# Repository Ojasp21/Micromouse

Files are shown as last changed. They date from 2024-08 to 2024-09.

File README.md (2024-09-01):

# Micromouse
Design a micromouse PCB from scratch and implement maze floodfill algorithms on it!  

## Table of Contents

- [Micromouse](#micromouse)
  - [Table of Contents](#table-of-contents)
  - [About The Project](#about-the-project)
  - [Project Workflow](#project-workflow)
  - [Hardware Used](#hardware-used)
  - [Perfboard Testing](#perfboard-testing)
  - [PCB Model](#pcb-model)
  - [CAD Models](#cad-models)
    - [Features](#features)
  - [Floodfill Algorithm Simulation](#floodfill-algorithm-simulation)
  - [Software Used](#software-used)
  - [Future Work](#future-work)
  - [Contributors](#contributors)
  - [Resources](#resources)
  - [Acknowledgements](#acknowledgements)
  - [License](#license)

## About The Project
The aim of this project is to design and assemble a full size micromouse which will use floodfill and other path finding algorithms to solve a maze.    

The dimensions of our full-size micromouse is 11.5 x 10 cm

## Project Workflow  
#### Research
- Learning and understanding Embedded C by referring to the firmware used in [SRA WallE](https://github.com/SRA-VJTI/Wall-E) and [MazeBlaze](https://github.com/SurajSonawane2415/MazeBlaze)
- Understanding what Micromouse is and how maze solving algorithms like floodfill actually work
- Deciding the constraints for our micrmouse and selecting hardware and electronic componenets accordingly. We did a detailed review of existing micromouse designs and features and arrived at our present design.
#### CAD and PCB Design
- Designing a CAD Model on [Onshape.com](https://www.onshape.com/en/). We went through various iterations and design options. After weighing the pro's and cons of a 4 motor design, we settled for a 2 motor design with a suction fan in the centre.
- PCB Design keeping mechanical design in mind during routing. Once the pcb design and routing is finalised, the order for the PCB is placed.
#### Perfboard Testing and PID
- Testing our pcb schematic on a perfboard and recreating the final micromouse design on a perfboard.
- Implementing PID on the perfboard Micromouse to refine the code and understand the implementation of control systems.
#### PCB Soldering and Assembly
- Once the PCB is delivered, we will solder the components onto the PCB and assemble the bot with the 3D-printed mounts
- After this, the testing of the final Micromouse in a 6ft x 6ft maze will begin.

## Hardware Used

| Components | Description |
| --- | --- |
| [ESP32 WROOM-E](https://robu.in/product/espressif-esp32-wroom-32e-16m-128mbit-flash-wifi-bluetooth-module/) | Microcontroller |
| [VL 5310X](https://robu.in/product/gy-53-vl53l0x-laser-tof-flight-time-ranging-sensor-module-serial-port-pwm-output/)  | ToF sensor4 |
| [DRV8833](https://robu.in/product/drv8833-2-channel-dc-motor-driver-module/) | Motor Driver |
| [N12 600 RPM With Encoders](https://robu.in/product/n12-2-4v-1200rpm-metal-gear-motor-with-encoder/) | Motors |
| [IR Sensors](https://robocraze.com/products/5mm-ir-transmitter-receiver-pair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) | Infrared Emitter-Receiver Pair |

## Perfboard Testing
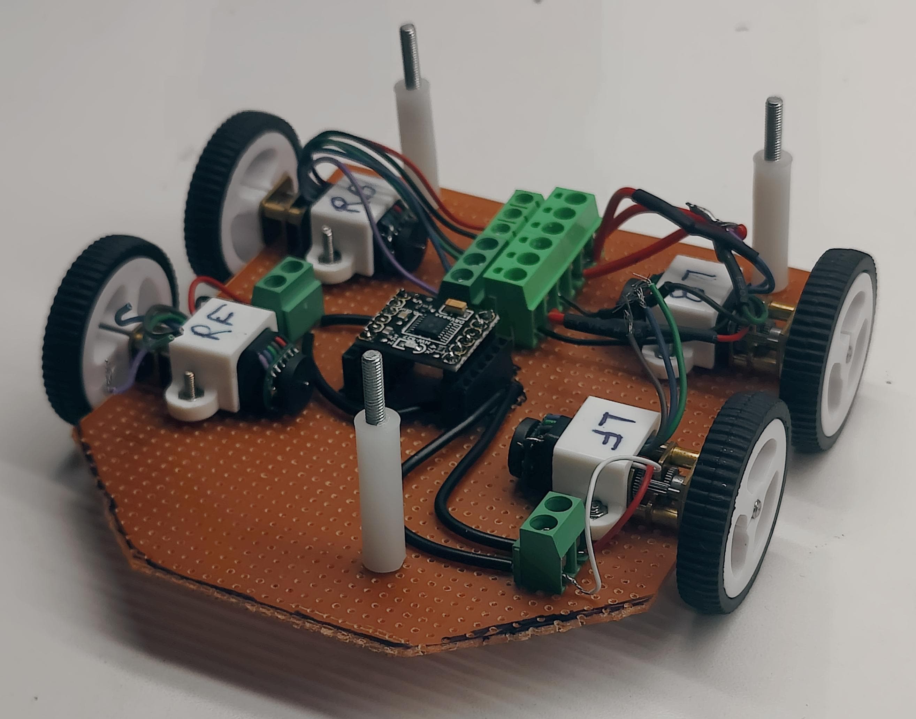
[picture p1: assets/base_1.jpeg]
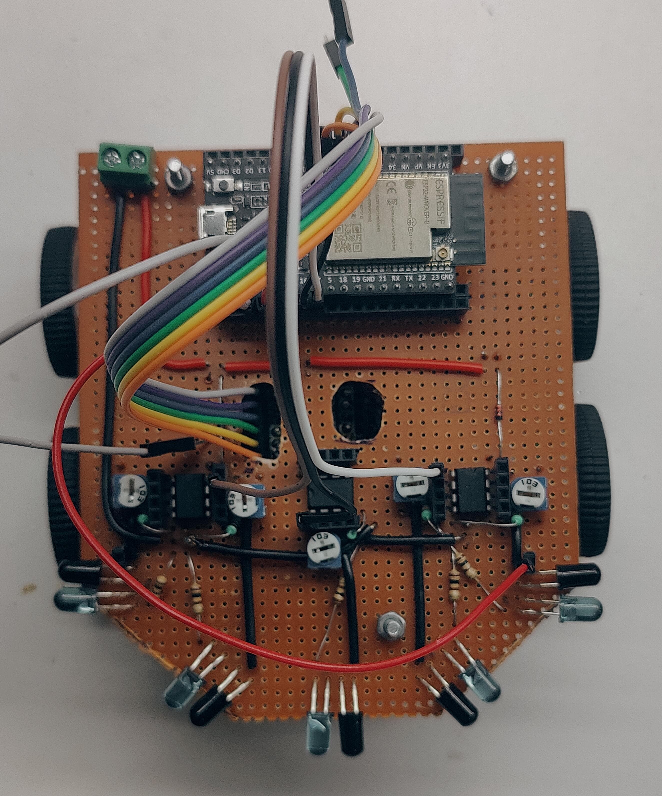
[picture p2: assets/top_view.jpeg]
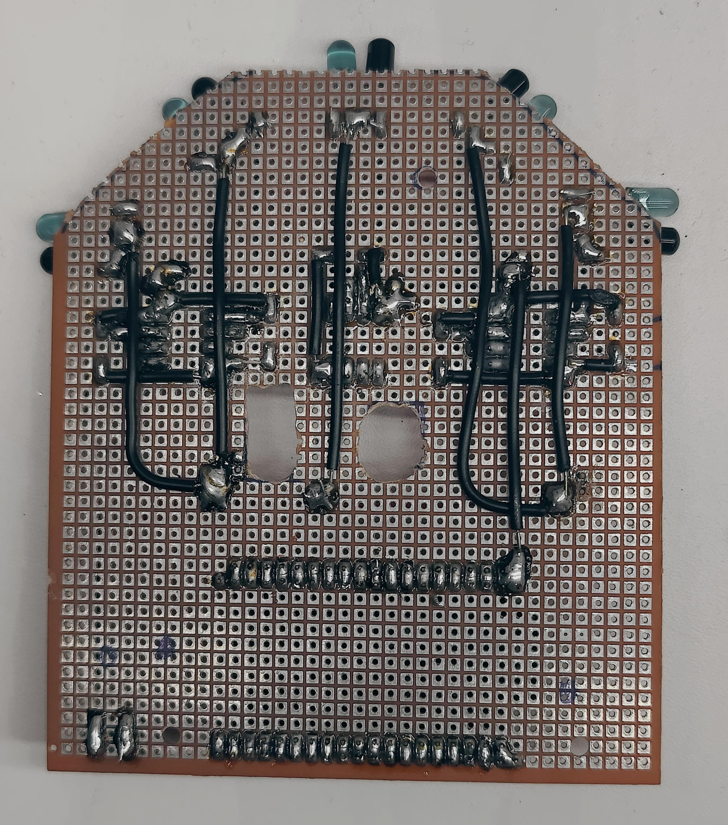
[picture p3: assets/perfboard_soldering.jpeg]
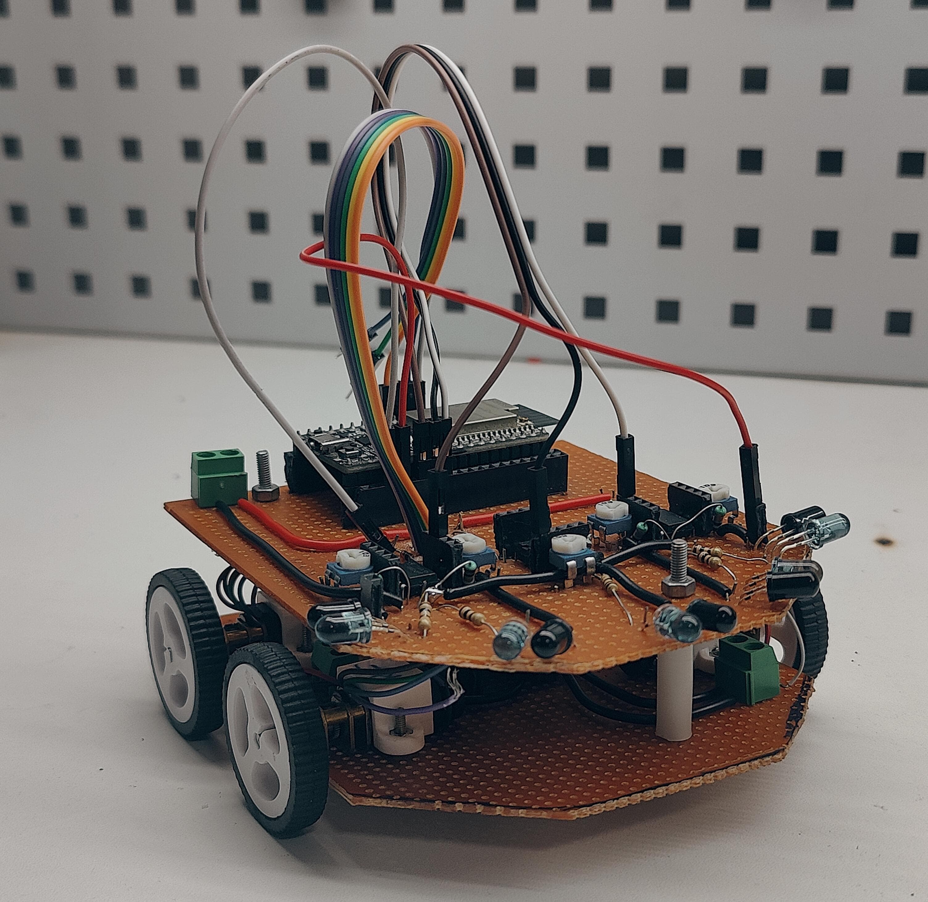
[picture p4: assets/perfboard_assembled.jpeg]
|             |  |  |  |
:-------------------------:|:-------------------------:|:-------------------------:|:-------------------------:

## PCB Model
- View of the PCB Model front and back:       
  
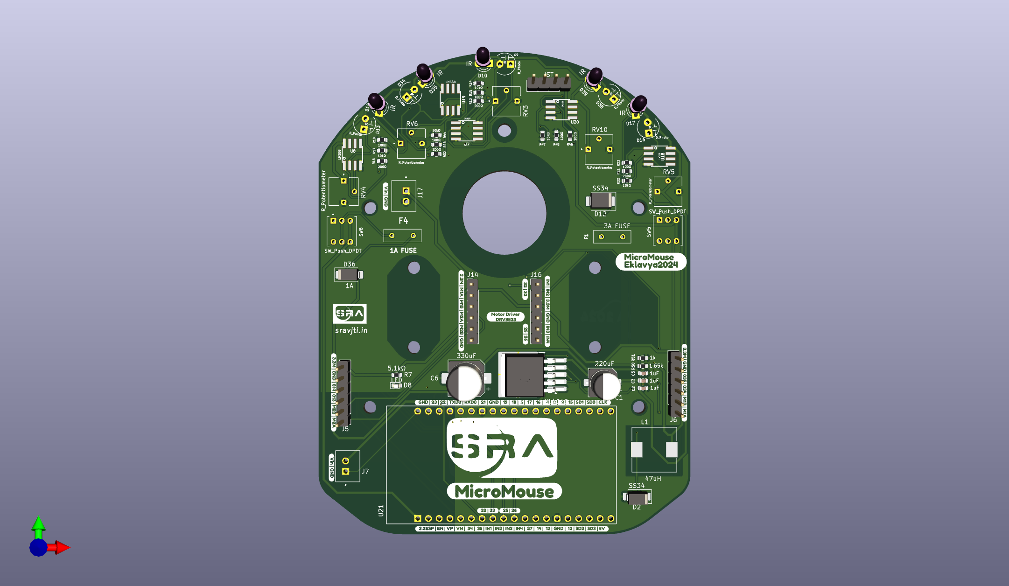
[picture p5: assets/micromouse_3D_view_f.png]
pcb_model_front
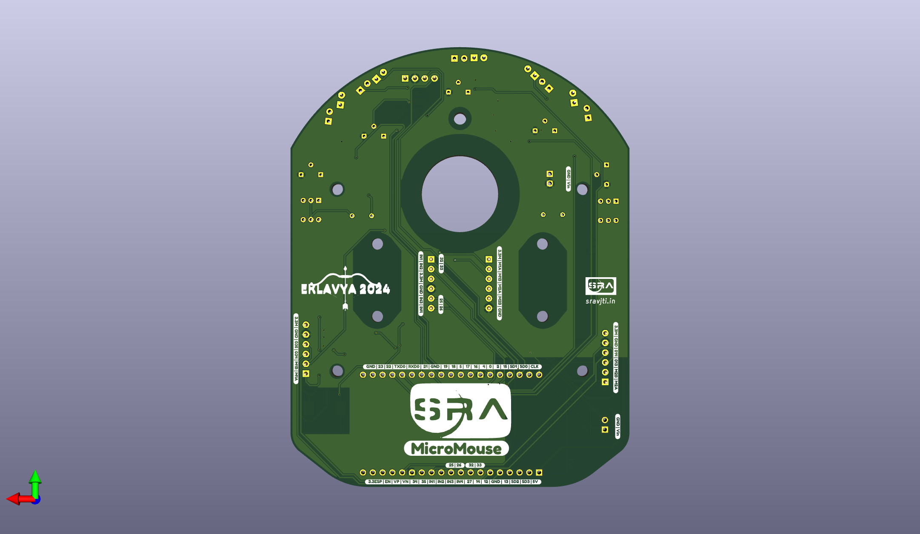
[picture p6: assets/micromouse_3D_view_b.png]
pcb_model_back
|             |  |    
:-------------------------:|:-------------------------:|

- View of the PCB Routing - front and back:      
  
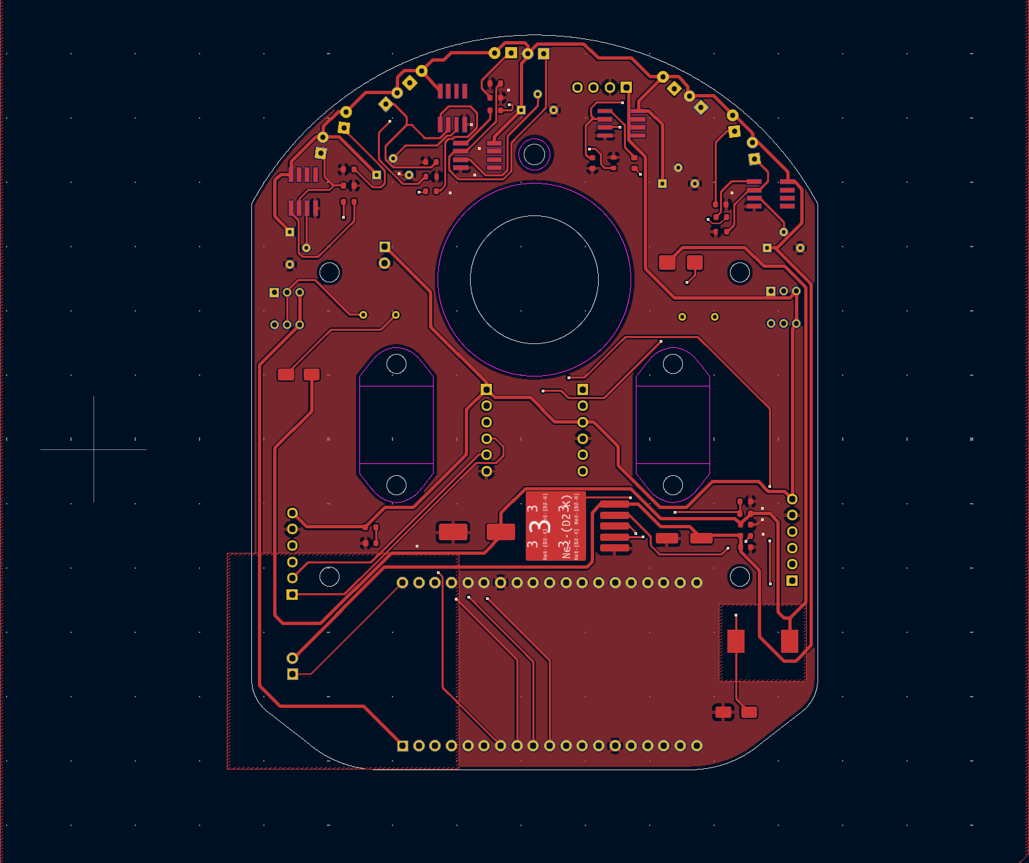
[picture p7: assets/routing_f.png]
pcb_routing_front
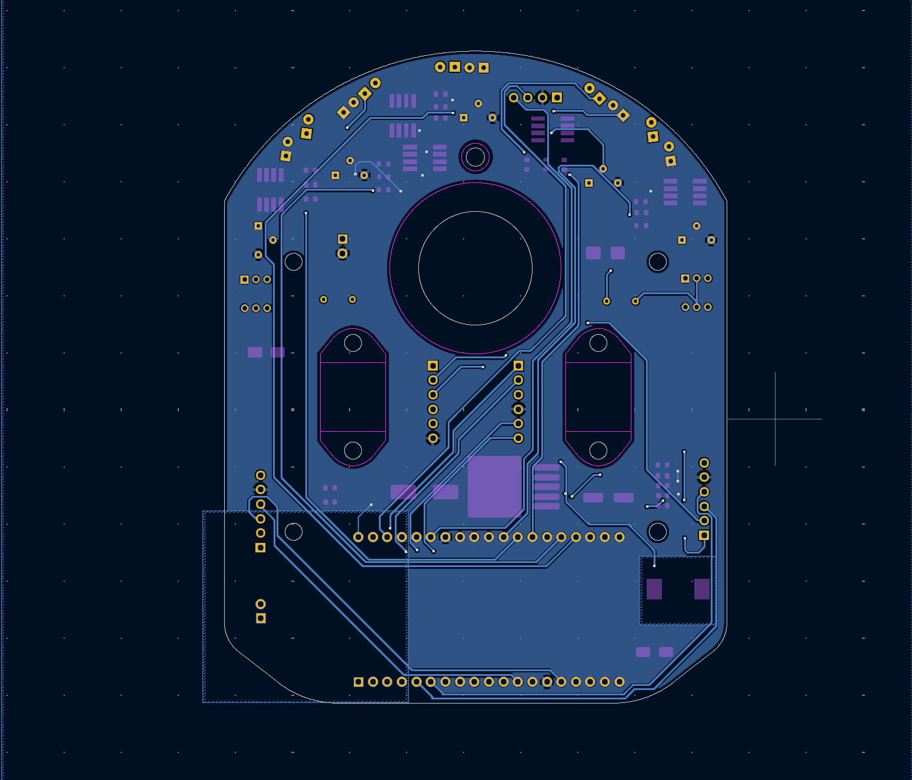
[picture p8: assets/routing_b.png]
pcb_routing_back
|             |  |  
:-------------------------:|:-------------------------:|

## CAD Models 
- First design iteration was a four motor design with a suction fan. However this design was not suitable for fitting an enitre Esp-Devkit. 

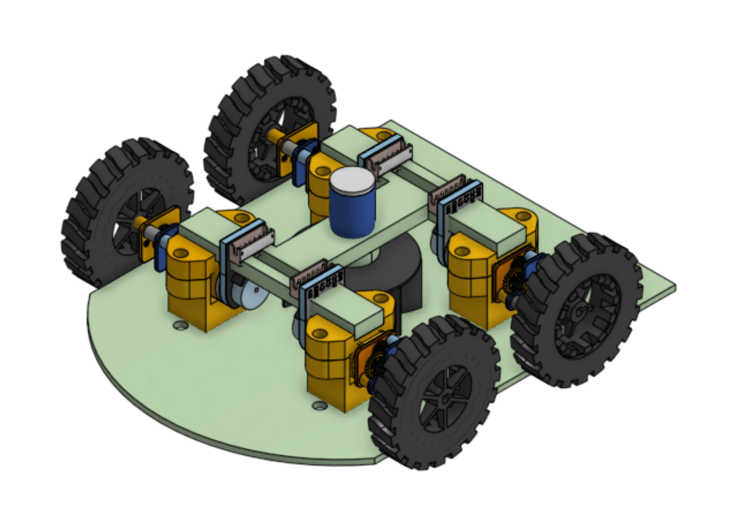
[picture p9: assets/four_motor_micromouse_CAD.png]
four_motor_design
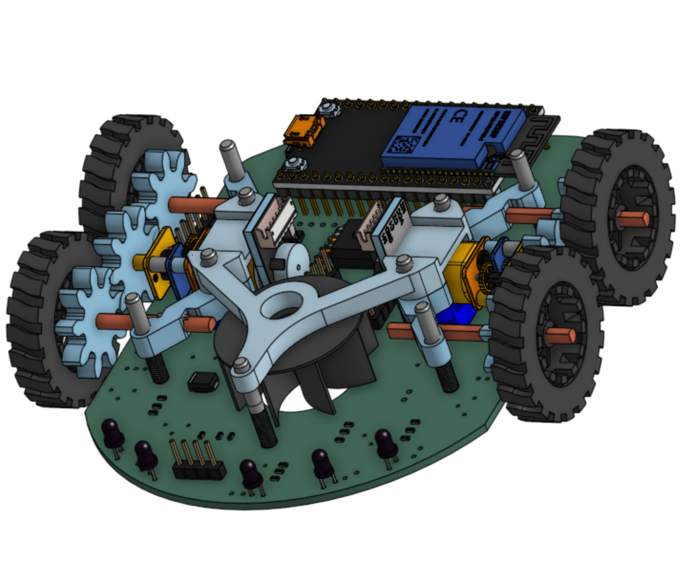
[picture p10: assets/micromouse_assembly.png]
two_motor_design
|             |  |  
:-------------------------:|:-------------------------:|

- Second and final design is a two-motor design with a suction fan. Certain drawbacks of the four-motor design was addressed in this design.  
<p align="center">
  
</p>

### Features 
- Suction Fan to improve traction and potentially turn at faster speeds without flipping over.  
- Custom mount to hold the motors, shaft and suction fan in place and reduce the distance between the plate and the ground.
-  Gears to run 4 wheels on two motors  
  
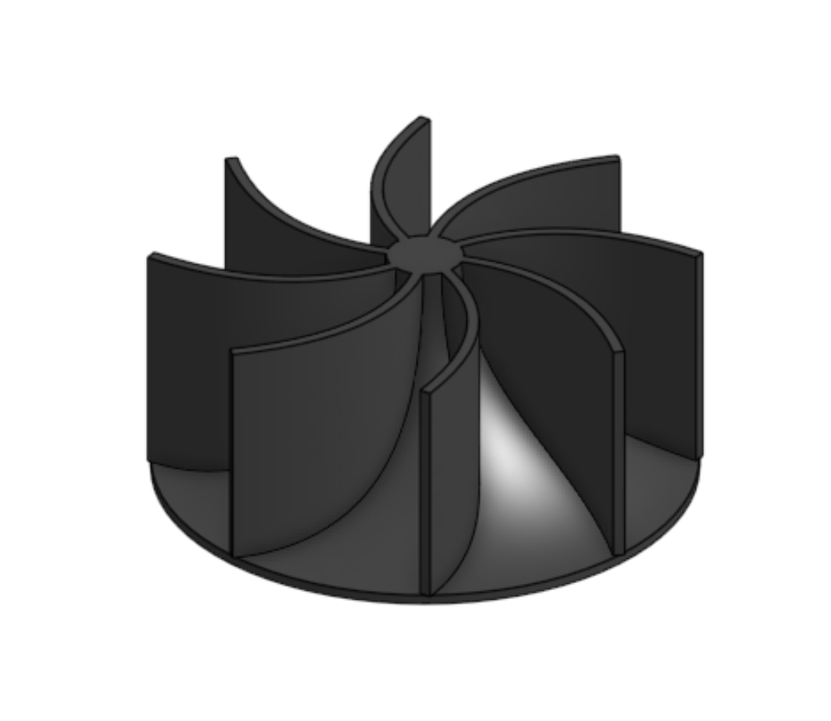
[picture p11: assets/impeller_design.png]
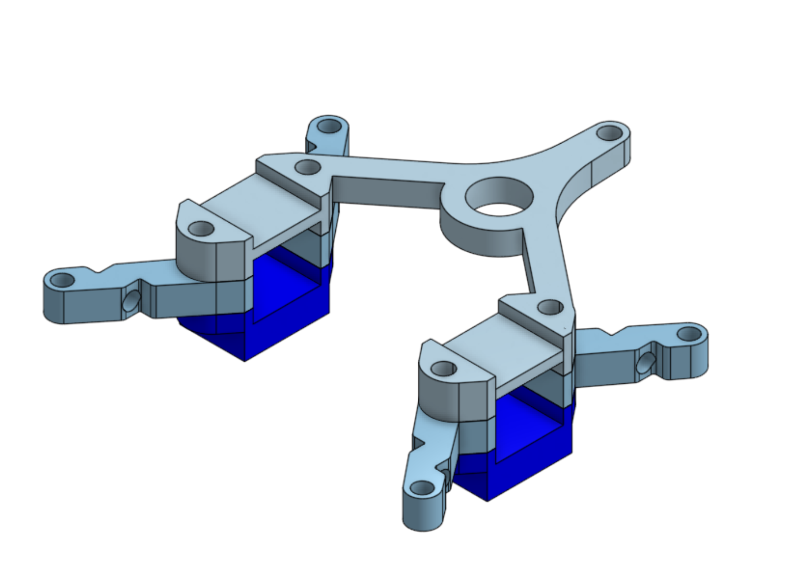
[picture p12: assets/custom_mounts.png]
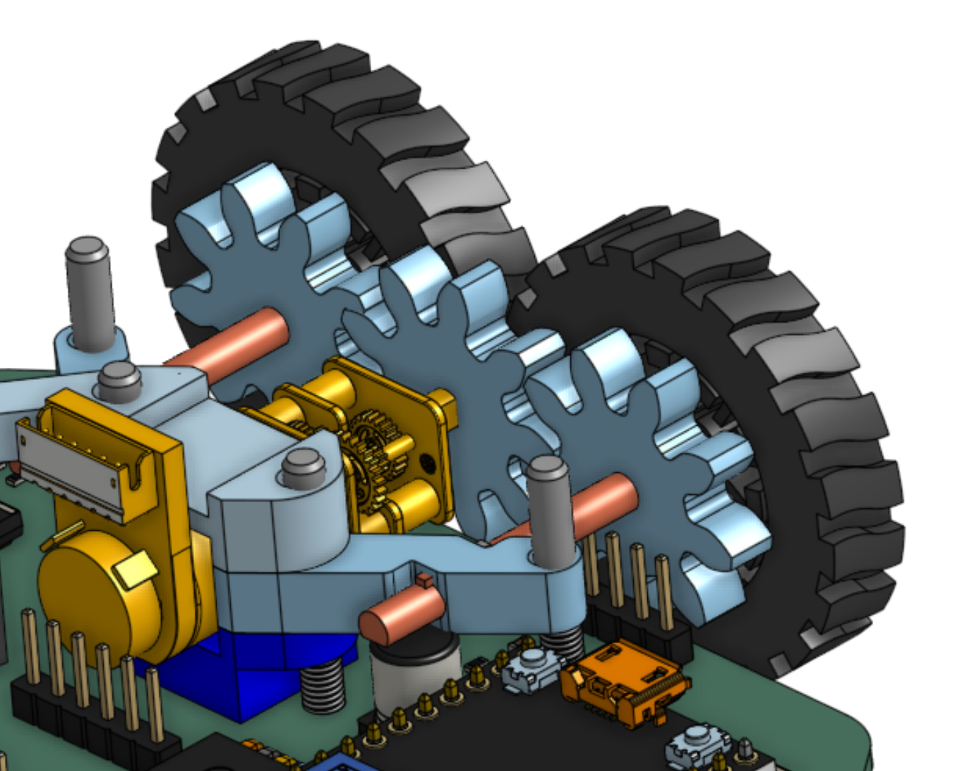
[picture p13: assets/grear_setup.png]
|             |  |  |
:-------------------------:|:-------------------------:|:-------------------------:|
  
## Floodfill Algorithm Simulation
The path solving algorithm floodfill has been successfully implemented in the software simulation.  
[Floodfill simulation](https://github.com/Ojasp21/Micromouse/blob/main/assets/flood%20fill%20simulation.mov)

## Software Used 
- Mechanical Design - [Onshape](https://www.onshape.com/en/)
- PCB Design - [KiCad 8.0.4](https://www.kicad.org/)
- Embedded C and Firmware - [ESP-IDF](https://docs.espressif.com/projects/esp-idf/en/stable/esp32/get-started/index.html)

## Future Work
- [ ] Implementing the flood-fill algorithm on it
- [ ] Optimizing the bot to achieve high speeds and taking turns as diagonals

## Contributors
- [Ojas Patil](https://github.com/Ojasp21)
- [Varun Nigudkar](https://github.com/fluffysunfish)
- [Vishal Mutha ](https://github.com/Vishal-Mutha)

## Resources
- [UCLA Micromouse Playlist](https://www.youtube.com/playlist?list=PLAWsHzw_h0iiPIaGyXAr44G0XfHfyjOe7) 
- [Mushak Github Repository](https://github.com/gautam-dev-maker/mushak/tree/main)
- [Mackorone MMS Github Repository](https://github.com/mackorone/mms) to run and test the floodfill simulation.

## Acknowledgements 
- [SRA VJTI](https://sravjti.in/) Eklavya 2024
- Special thanks to our mentors [Atharva Atre](https://github.com/AtharvaAtre), [Suraj Sonawane](https://github.com/SurajSonawane2415), and all the seniors at SRA, VJTI for their constant support and guidance throughout the project.

## License
[MIT License](https://opensource.org/license/mit/)

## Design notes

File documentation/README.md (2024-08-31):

# *DOCUMENTATION*
Documentation for presentation of [EKLAVYA-SRA](https://eklavya.sravjti.in/projects/) project - [MICROMOUSE](https://eklavya.sravjti.in/projects/Micromouse/) 

## **What is Micromouse?**  
Micromouse is a small, autonomous robot designed to navigate and solve a maze. It is a popular robotics competition where participants build and program a robot (“mouse”) to autonomously find its way from a starting point to the center of a maze in the shortest possible time. The competition combines aspects of ***robotics, algorithm development, and engineering design***, making it a challenging and educational project for students, hobbyists, and professionals alike.  

----

### **Key Objectives of a Micromouse Competition:**  
The primary goal in a Micromouse competition is to design a robot that can:  
- **Autonomously Navigate:** The Micromouse must move through a maze without human intervention. It relies on onboard sensors, microprocessors, and algorithms to make decisions in real-time.  
  
-	**Efficiently Solve the Maze:** The robot must find the shortest or fastest route to the goal, usually the center of the maze, from a starting corner. This involves exploring unknown paths, detecting dead-ends, and backtracking when necessary.  

-	**Optimize Time and Path:** The robot’s success is typically measured by the time it takes to reach the goal and the efficiency of the path taken. Robots are expected to minimize turns, backtracks, and wall collisions to achieve the fastest time.

### **Core Components of a Micromouse:**  
1.	**Microcontroller**: Acts as the “brain” of the robot, processing inputs from sensors and executing maze-solving algorithms. Common microcontrollers used are Arduino, ESP32, or STM32.

2.	**Sensors**: Typically, Infrared (IR) sensors or Time-of-Flight (ToF) sensors are used to detect walls and measure distances, helping the robot navigate through the maze accurately.

3.	**Motors and Motor Drivers**: The Micromouse uses small DC motors or stepper motors for movement, controlled by motor drivers like the DRV8833, which regulate speed and direction.

4.	**Algorithms**: Efficient maze-solving algorithms, such as Flood-Fill, Wall-Following, A*, or Dijkstra’s algorithm, are implemented to ensure the mouse navigates optimally.

5.	**Power Supply**: A compact power source, like a 3.7V lithium-ion battery, is used to power all components while keeping the weight and size minimal.

## **Educational and Practical Value:- Domains explored**   
The Micromouse competition offers significant learning opportunities in embedded systems, control theory, robotics, artificial intelligence, and mechanical design. It encourages participants to innovate, optimize algorithms, and build practical skills in programming and electronics. The competition’s real-world challenges, such as sensor noise, motor control, and algorithm efficiency, make it an excellent platform for learning and experimentation.  

----
### **Maze solving algorithms:**  
Maze-solving algorithms are crucial for enabling a Micromouse robot to navigate through a maze efficiently and reach a designated goal, typically the maze’s center. These algorithms determine the path by processing real-time data from sensors and making decisions based on the maze’s layout.Some of the most popular algorithms include the **Flood-Fill algorithm**, which dynamically updates a grid map by assigning values to each cell, allowing the robot to always move toward the cell with the lowest value, thus finding the shortest path to the goal.  
Another common approach is the **Wall-Following algorithm**, such as the Left or Right Wall Following, which directs the robot to follow one side of the maze walls until it reaches the goal. More advanced algorithms, like **A**\* and **Dijkstra’s algorithm**, calculates the most efficient path by considering both the distance and cost associated with each possible move, ensuring optimal navigation. The choice of algorithm depends on the maze’s complexity and the desired balance between speed, accuracy, and computational efficiency.

## **Flood-Fill Algorithm:**  
The Flood-Fill algorithm is a systematic way of exploring the maze, updating the shortest path dynamically as new information about the maze is discovered.

FloodFill_CELL_VALUES

### **Working Principle:**  
1.	**Initialization**:  
    - The goal cell (usually the center of the maze) is set to 0\.  
	- All other cells are initialized with a high value, indicating a “flooded” or unvisited state. 
   
2.	**Updating Cell Values**:  
	- Starting from the goal cell, each adjacent cell is assigned a value one greater than the current cell.  
	- This process continues until all reachable cells are assigned values representing the number of steps required to reach the goal.
  
3.	**Mouse Movement**:  
	- The mouse always moves to the adjacent cell with the lowest value. This ensures it is moving toward the goal.  
	- As the mouse explores and detects walls, the values are recalculated to account for these new obstacles. Cells adjacent to walls have their values increased.
  
4. **Handling Dead-Ends and Backtracking**:  
    - If a dead-end is reached, the mouse will backtrack to the nearest cell with an alternative path. The algorithm dynamically updates the flood values to reflect the most efficient path.

## **Advantages of Flood-Fill:**
- **Optimal Pathfinding**: Guarantees the shortest path by continuously updating the maze’s knowledge.
    
- **Adaptability**: Reacts dynamically to new information about the maze structure.
  
- **Efficiency**: Minimizes unnecessary movements and backtracks, saving time and battery.    
  
---
### **Testing Flood-Fill Algorithm :**  

<p align="center">
  
</p>

#### To test the Flood-Fill algorithm in a simulation:  
- Set Up Different Maze Configurations: Create varying levels of maze complexity to ensure the algorithm adapts and recalculates paths effectively.  
- Simulate Sensor Accuracy: Use realistic sensor data from the simulation to mimic actual wall detection and noise.  
- Measure Performance Metrics: Track the time taken to reach the goal, the number of recalculations, and the total distance traveled to evaluate algorithm efficiency.  
- Optimize Parameters: Fine-tune the sensor sensitivity, robot speed, and recalculation intervals to improve performance based on the test results.

## **Left Wall Following Algorithm:**  
The Left Wall Following method is a simpler heuristic-based algorithm that instructs the Micromouse to always follow the left wall of the maze. This method is useful for exploring mazes that do not have isolated areas or loops. 

#### **Working Principle:**

1. **Initial Movement**:  
   - The mouse starts from the initial position and moves forward while checking for walls.
  
2. **Always Turn Left**:  
   - When encountering an intersection or corner, the mouse prioritizes turning left if there is no wall.  

   - If a wall is present on the left, it will continue moving forward until a left turn is possible.  

   - If both left and forward paths are blocked, the mouse turns right.  

3. **Handling Dead-Ends**:  
   - When reaching a dead-end, the mouse turns 180 degrees to backtrack and follows the same left-wall rule.  

4. **Reaching the Goal**:  
    - The mouse continues following the left wall until it reaches the center of the maze or the designated goal.

## **Advantages of Left Wall Following:**  
- **Simplicity**: Easy to implement with minimal computational requirements.  
  
- **Predictable**: Provides a straightforward way to navigate simple mazes.  

- **Quick Exploration**: Ideal for initial maze exploration to map walls and potential paths.
-----

#### **Testing Left Wall Following Algorithm:**
To test the Left Wall Following algorithm in a simulation:  

- **Set Up Various Mazes**: Include mazes with no isolated sections, loops, or walls that form a continuous boundary to test the effectiveness of the Left Wall Following method.

- **Simulate Sensor Inputs**: Mimic real-world sensor behavior to detect walls and ensure reliable decision-making for turning.  
  
- **Evaluate Performance**: Measure the time to complete the maze, the number of turns, and the efficiency of the path taken compared to the optimal path.  

- **Identify Limitations**: Test in more complex mazes to understand scenarios where the Left Wall Following method may not yield the shortest path or may get stuck in loops.
-----

# **Start of the project…..**

## **Perfboard Testing for Micromouse:**
Perfboard testing is an essential step in the development process of a Micromouse robot. A perfboard (short for perforated board) is a prototyping board used to build circuits without the need for designing and manufacturing a printed circuit board (PCB) right away. It allows developers to test the functionality of various components, such as sensors, motor drivers, and microcontrollers, before finalizing the design. This approach provides a flexible and cost-effective way to verify that all components work as intended when integrated.

| PERFBOARD_IMAGE_1 | PERFBOARD_IMAGE_2 |
:------------------|:-----------------:|

### **Purpose of Perfboard Testing:**  
1. **Circuit Validation**: Ensures that all components are correctly wired and interact as expected. This step is crucial to identify any electrical issues, such as incorrect connections or voltage mismatches, which could lead to component failure.  
2.	**Functional Testing**: Allows testing of the Micromouse’s core functionalities—like motor control, sensor readings, and microcontroller processing—in a controlled environment. This helps in validating that the hardware and software communicate properly.  
3.	**Debugging and Optimization**: Provides a platform for real-time debugging. One can easily replace components, adjust connections, or tweak circuit parameters without the complexities associated with a final PCB layout.

### **Steps for Perfboard Testing:**  
1.  **Component Placement and Soldering**:  
    - Carefully place all components—such as microcontrollers (ESP32), motor drivers (DRV8833), IR sensors, and Time-of-Flight (ToF) sensors—on the perfboard in a logical layout that minimizes wire length and prevents cross-connections.  
	- Solder the components securely, ensuring no cold joints or short circuits between adjacent pads. Proper soldering techniques are crucial to avoid unstable connections.  
2.  **Power Supply Verification**:  
	- Connect the power source (e.g., 3.7V battery) to the perfboard and verify the voltage levels across different sections of the circuit. Use a multimeter to ensure that all components receive their required voltage and current levels.  
3.  **Initial Power-On Testing**:  
	- Perform a “smoke test” by powering on the circuit with minimal components to check for immediate signs of faults, such as overheating components, unusual noises, or visible smoke.  
4.  **Subsystem Testing**:  
	- Motor and Motor Driver Testing: Verify that the motors respond correctly to the control signals from the motor driver and microcontroller. Test different speeds and directions.  
	- Sensor Testing: Confirm that the sensors (IR sensors, VL53L0X ToF sensors) provide accurate readings and that data is correctly processed by the microcontroller.  
	- Microcontroller Functionality: Ensure the microcontroller executes the maze-solving algorithms correctly and interfaces with all other components without errors.  
5.	**Integration Testing**:  
	- Once all individual components and subsystems are tested, perform an integrated test to see how they work together. This step involves running simple maze-solving algorithms, like wall-following, to ensure the robot moves and navigates properly.

### **Benefits of Perfboard Testing:**  
- Flexibility and Easy Modifications: Components can be easily removed or replaced without the need to manufacture a new PCB.  
- Cost-Effective: Helps in identifying issues early in the development cycle, saving costs associated with faulty PCB design or incorrect component selection.  
- Prototyping Speed: Accelerates the prototyping process, allowing for rapid iterations and testing of different circuit designs or configurations.

## **Cad Model:**
| four_motor_design            | two_motor_design |  
:-------------------------:|:-------------------------:|

<p align="center">
  
</p>

## **PCB Designing :**
| pcb_model_front            | pcb_model_back |    
:-------------------------:|:-------------------------:|

| pcb_routing_front            | pcb_routing_back |  
:-------------------------:|:-------------------------:|

## **What is PCB Design?**  
PCB (Printed Circuit Board) design involves creating a physical layout for a board that supports and electrically connects electronic components. The process includes schematic capture, layout design, component placement, routing, and verification.  

### **Key Components of PCB Design:**  
- **Schematic Design**: The first step in PCB design, where electronic circuits are made using CAD tools to define electrical connections between components.  

- **PCB Layout**: Involves designing the physical layout of the board, defining its shape, and placing components based on the schematic.  

- **Routing**: Establishing electrical paths (traces) that connect various components on the board, which is crucial for signal integrity and reducing noise.  

- **Verification and DFM Checks**: Ensures the design is functionally correct and manufacturable. DFM (Design for Manufacturing) checks help identify potential issues before production.

### **Tools for PCB Design:**  

- **KiCad**: A widely-used open-source PCB design tool that supports schematic capture, PCB layout, and DFM checks.  

- **Other Tools**: Eagle, Altium Designer, and OrCAD are other popular tools used in professional PCB design.

#### **Basic Steps in PCB Design Using KiCad:**  
1. **Create Schematic**: Define components and their connections.  

2. **Assign Footprints**: Link each schematic symbol to its corresponding physical footprint.  

3. **Design Board Layout**: Arrange components and define the board’s shape and size.  

4. **Route Traces**: Connect components following design rules to ensure electrical performance.  

5. **Run DFM Checks**: Verify that the design is free from errors that could cause manufacturing issues.

## **Power and Sensor Circuitry Design for Micromouse :**

### **Introduction to Power and Sensor Circuitry:**  
The Micromouse project involves designing a PCB that integrates multiple components, such as motor drivers, distance sensors, and voltage regulators, to navigate a maze autonomously. Key components include the DRV8833 motor driver, VL53L0X ToF sensor, IR sensors, and the XL4015 voltage regulator.

#### **Using XL4015 in PCB Design:**  

- **XL4015 Overview**: A high-efficiency, step-down (buck) DC-DC converter providing up to 5A output current. It is used in the design to manage power supply for the Micromouse components.  

- **Key Considerations**:  
  
  - **Thermal Management**: Ensure sufficient copper pours and thermal vias to dissipate heat generated by the regulator.  
  
  - **Capacitor and Inductor Selection**: Use low ESR capacitors for stability and select inductors based on current and ripple requirements.  
  
  - **Layout Tips**: Minimize trace lengths for the input and output capacitors to reduce noise. Use a solid ground plane for improved stability.

#### **Integrating DRV8833 Motor Driver:**  

- **DRV8833 Overview**: A dual H-Bridge motor driver capable of driving two DC motors or one stepper motor. It is used for controlling the Micromouse’s motors.  

- **Key Considerations**:  
	
	- **Heat Dissipation**: Ensure adequate heat sinking and thermal vias for cooling the motor driver.  
	
	- **Routing Strategy**: Use wide traces for motor supply lines to handle high current. Keep control signal traces short to avoid noise interference.  
	
	- **Placement**: Position the DRV8833 close to the motors to reduce trace inductance and resistive losses.

#### **Integrating VL53L0X ToF Sensor:**  

- **VL53L0X Overview**: A Time-of-Flight (ToF) sensor used for distance measurement, critical for detecting walls in the maze.  

- **Key Considerations**:  
	
	- **I2C Communication**: Ensure proper pull-up resistors are in place for I2C lines. Keep the traces short to avoid signal degradation.  
	
	- **Component Placement**: Place the sensor on the front side of the Micromouse to maximize its field of view.

#### **Using IR Sensors:**  

- **IR Sensors Overview**: Used for close-range object detection and alignment in the maze.  
	
	- **Key Considerations**: Important for PID tuning of the bot for moving in the straight path.  
    
	- **Analog Signal Integrity**: Ensure clean analog ground planes and minimize noise by separating analog and digital signals.  
	
	- **Placement Strategy**: Position IR sensors around the perimeter of the Micromouse to cover all directions for effective wall-following algorithms.

#### **Using 3.7V battery:**  

- The mouse is powered by  a 3.7V battery, which provides a compact and efficient power source suitable for driving the components like the DRV8833 motor driver and sensors.   

- Proper regulation using the XL4015 ensures stable voltage levels for reliable operation.

### **Resolving DFM Issues that we faced and Tips in KiCad:**
---

#### **Common DFM Issues in PCB Design:**  

- **Component Spacing**: Ensure sufficient spacing between components to allow for effective soldering and heat dissipation.  

- **Trace Width and Spacing**: Validate trace widths based on current-carrying requirements and maintain proper spacing to prevent short circuits.  

- **Silkscreen Overlap**: Avoid placing silkscreen over solder pads to prevent soldering issues.  

- **Via Size and Placement**: Use adequately sized vias to handle required current and minimize parasitic effects.

#### **Addressing DFM Issues in KiCad:**  

- **Design Rule Checks (DRC)**: Run DRC in KiCad to identify and correct design rule violations, such as insufficient trace width or clearance.  

- **Layer Stackup Management**: Properly define the layer stack-up to ensure signal integrity, reduce noise, and provide effective grounding.  

- **Assembly Information**: Provide detailed assembly information, such as component part numbers, orientations, and placement guidelines.  

- **Solder Mask and Paste Layer Checks**: Ensure that the solder mask does not cover solder pads and that the paste layer aligns correctly for effective soldering.

### **Advanced Tips for Optimizing PCB Design :**  

- Thermal Analysis: Conduct thermal simulations to predict heat distribution and optimize the placement of thermal vias and copper pours for better heat dissipation.  

- Signal Integrity Analysis: For high-speed designs, consider impedance matching to avoid signal reflections and degradation.  

- Component Placement Strategy: Optimize placement for better electrical performance and assembly ease. Keep power components like the XL4015 away from sensitive analog circuits.  

- Documentation and Output Files: Generate comprehensive documentation, including Gerber files, drill files, and the Bill of Materials (BOM), for seamless manufacturing.

## **Simulation for Maze solving :**

### **Introduction to Micromouse Maze Solving:**

Micromouse maze-solving is a robotics competition where an autonomous robotic mouse (Micromouse) navigates a maze to reach the center in the shortest time possible. The maze-solving algorithm, combined with accurate sensor data and efficient motor control, plays a critical role in the Micromouse’s success.  

### **Simulation Benefits**:  

Running a simulation for a Micromouse maze-solving project offers several advantages:  

- **Algorithm Testing**: Allows developers to test and refine their maze-solving algorithms without the need for physical hardware.  

- **Error Debugging**: Enables identification of logical errors and optimizes the robot’s decision-making processes.  

- **Cost Efficiency**: Reduces the cost and time associated with repeated physical trials and hardware wear and tear.

### **Simulation Environment Setup:**  

1. **Software Requirements**:  

   - We have used a online simulation for our bot with custom API’s  

   - We have used an online simulator for micromouse and used its environment related API’s.  

2.	**Modeling the Micromouse**:  
	
	- Create or import a 3D model of the Micromouse with accurate dimensions and physical properties.  
    
	- Define sensors (e.g., IR sensors, ToF sensors) and actuators (e.g., motor drivers) in the simulation environment. Ensure that these are correctly parameterized to match the real-world counterparts.  

3.	**Maze Environment Setup**:  
   
    - Design the maze according to competition rules, with defined wall thickness, cell size, and possible obstacles.  
    
	- Set up the maze as an environment file in the simulation software. Include parameters for ground friction, wall material, and any other environmental factors affecting movement.

### **Integration of Maze-Solving Algorithms:**  

- **Algorithm Types**:  
	
	- Implement algorithms such as left wall following and floofill.  
	
	- Optimize algorithms to account for pathfinding efficiency and avoid unnecessary turns or backtracking.  

- **Programming the Robot**:  
	
	- Write code for movement control, sensor data processing, and decision-making based on sensor inputs.  
	
	- Implement an API that allows communication between the simulation environment and the maze-solving code.

## **What’s next..**

1. We will be building a maze with the help of ply and after assembling our pcb, start with the testing.  

2. Rectify the mistakes in our design and will make a new pcb for the next iteration.  

3. Then target the implementation of different algorithms.

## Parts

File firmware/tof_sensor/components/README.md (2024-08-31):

# ESP-IDF component for VL53L0X ToF distance sensor
Based on VL53L0X_1.0.4 API version.

## Notes
In order to compile the program correctly, change following option in `menuconfig`:

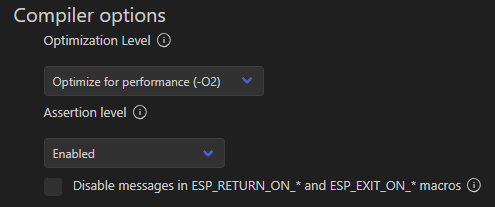
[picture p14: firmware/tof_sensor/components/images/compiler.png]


## Sources
* https://github.com/kerikun11/ESP32_VL53L0X
* https://www.st.com/resource/en/datasheet/vl53l0x.pdf
* https://www.st.com/en/embedded-software/stsw-img005.html#overview

## Example
```C
#include <stdio.h>
#include "freertos/FreeRTOS.h"
#include "freertos/task.h"
#include "esp_log.h"
#include "vl53l0x.h"

#define I2C_PORT    I2C_NUM_1
#define SDA_PIN     GPIO_NUM_27
#define SCL_PIN     GPIO_NUM_19
#define GPIO1_PIN   GPIO_NUM_26
#define XSHUT_PIN   -1
#define I2C_FREQ    400000

static const char *TAG = "main";

void app_main(void)
{
    vl53l0x_conf_t vl53l0x_conf = {
        .i2c_port = I2C_PORT,
        .sda_pin = SDA_PIN,
        .scl_pin = SCL_PIN,
        .i2c_freq = I2C_FREQ,
        .xshut_pin = XSHUT_PIN,
        .gpio1_pin = GPIO1_PIN
    };
    vl53l0x_init(vl53l0x_conf);

    // measurement
    while (1)
    {
        uint16_t result_mm = 0;
        TickType_t tick_start = xTaskGetTickCount();
        bool res = vl53l0x_read(vl53l0x_conf, &result_mm);
        TickType_t tick_end = xTaskGetTickCount();
        int32_t took_ms = (int32_t)(tick_end - tick_start) / portTICK_PERIOD_MS;
        if (res)
            ESP_LOGI(TAG, "Range: %hu [mm] took %ld [ms]", result_mm, took_ms);
        else
            ESP_LOGE(TAG, "Measure failure");
    }
}
```

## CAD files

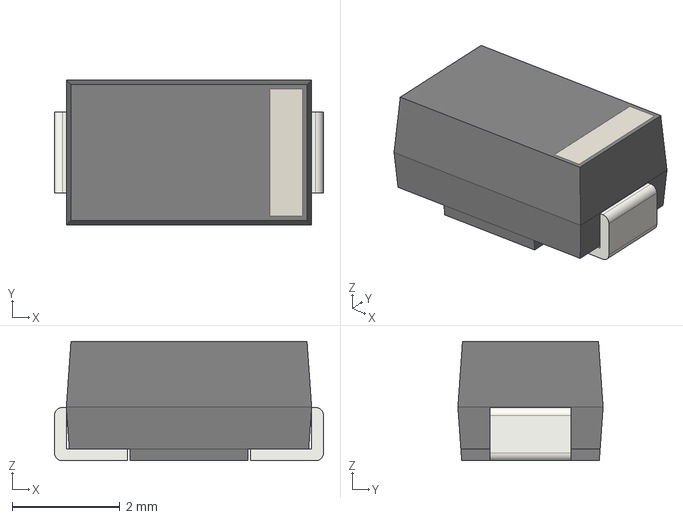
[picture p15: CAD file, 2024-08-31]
cad_design/2_motor_assembly/Assembly 3 - D_SMA.step
5.00 x 2.70 x 2.22 mm

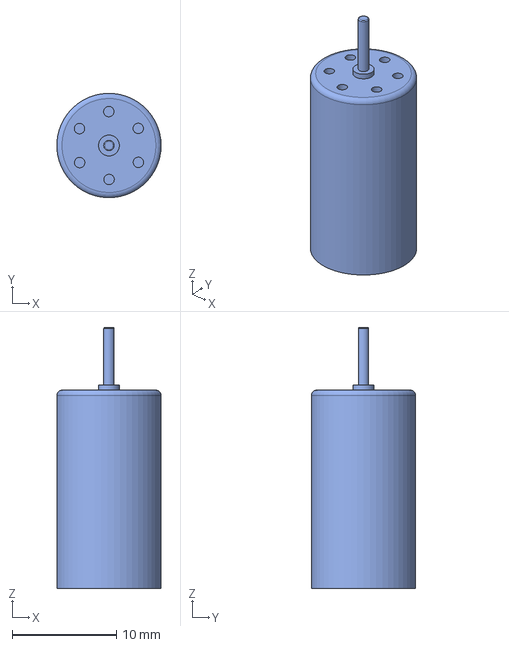
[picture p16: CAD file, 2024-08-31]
cad_design/4_motor_assembly/Assembly 1 - 1020 Coreless Motor v3 v2.step
9.99 x 10.00 x 25.0 mm

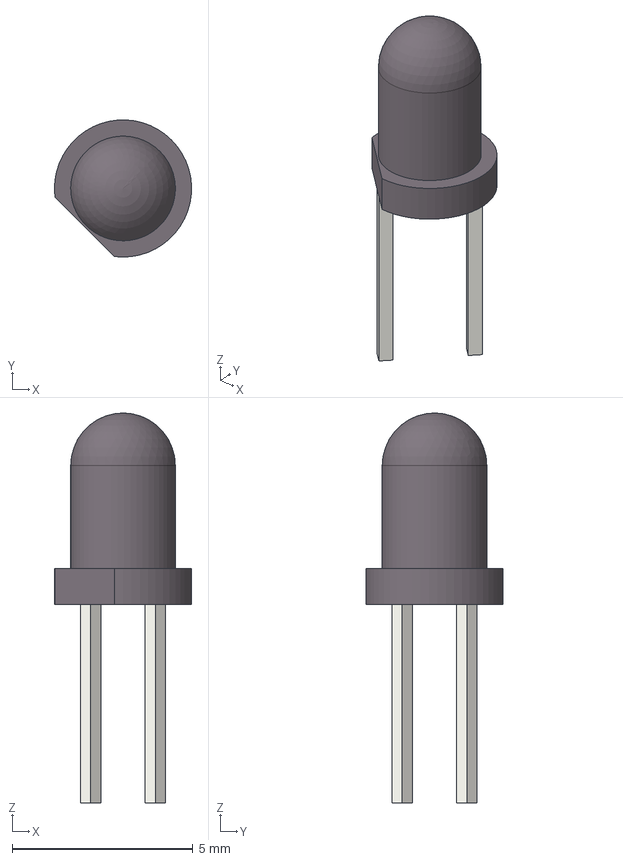
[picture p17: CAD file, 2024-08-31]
cad_design/2_motor_assembly/Assembly 3 - LED_D3.0mm_IRBlack.step
3.80 x 3.80 x 10.8 mm

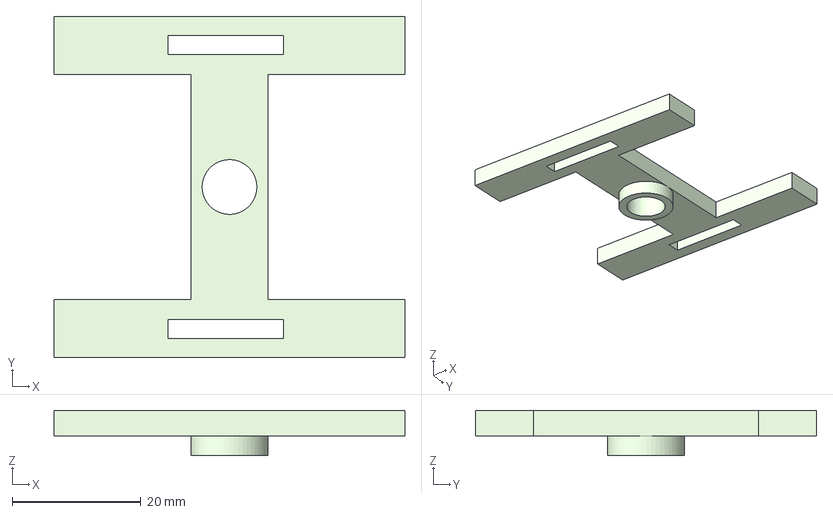
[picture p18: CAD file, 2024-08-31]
cad_design/4_motor_assembly/Assembly 1 - Part 14.step
54.5 x 53.0 x 7.00 mm

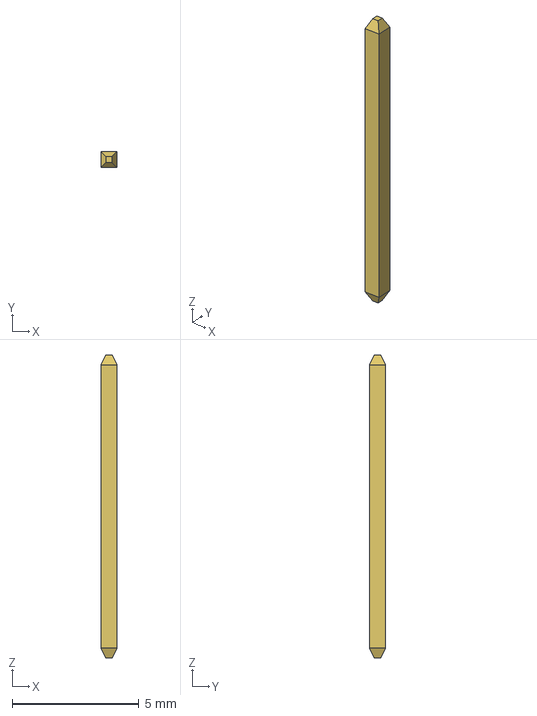
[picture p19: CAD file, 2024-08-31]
cad_design/2_motor_assembly/Assembly 3 - zl201-19_p2-54_l48-3_w2-54_h8-9 (15).step
0.65 x 0.65 x 11.9 mm

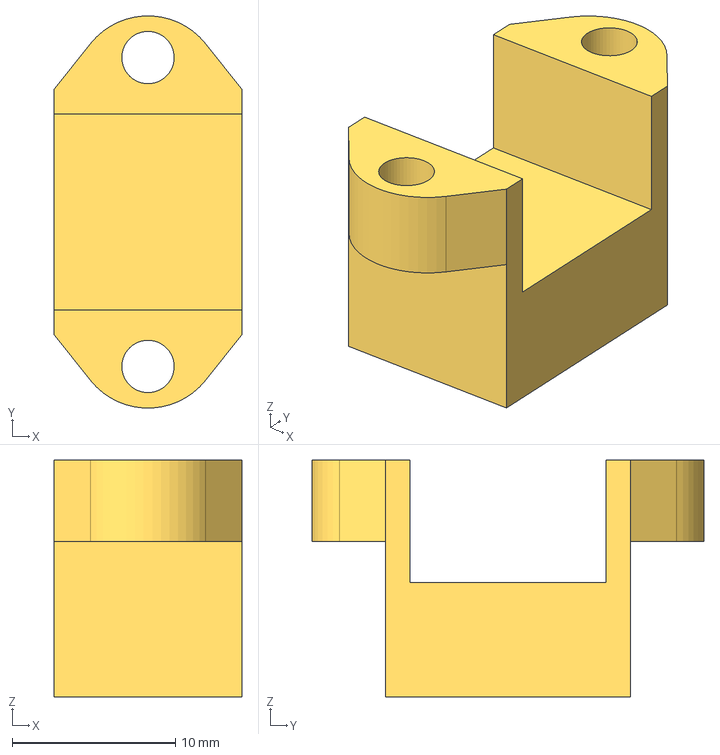
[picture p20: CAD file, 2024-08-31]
cad_design/4_motor_assembly/Assembly 1 - Mount 1_B.step
11.5 x 24.0 x 14.5 mm

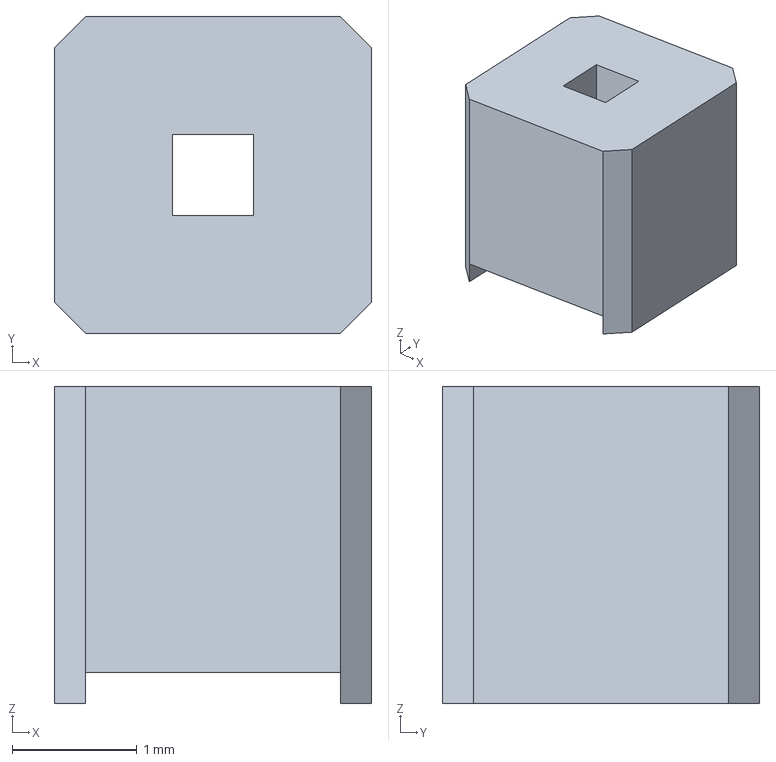
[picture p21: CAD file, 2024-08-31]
cad_design/2_motor_assembly/Assembly 3 - zl201-19_p2-54_l48-3_w2-54_h8-9 (4).step
2.54 x 2.54 x 2.54 mm

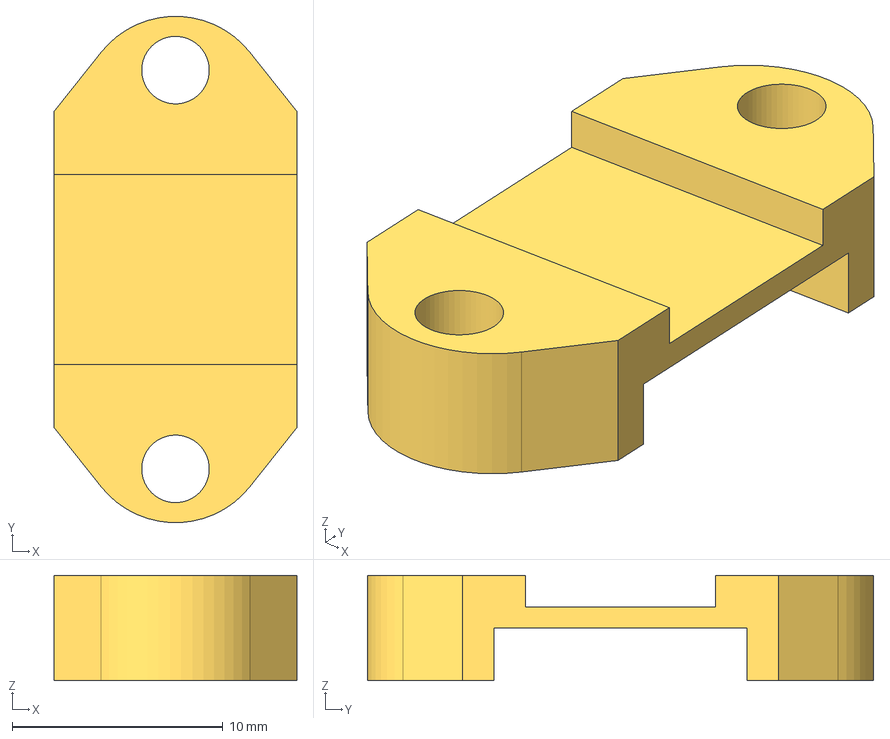
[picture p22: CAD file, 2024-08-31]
cad_design/4_motor_assembly/Assembly 1 - Mount 4_T.step
11.5 x 24.0 x 5.00 mm

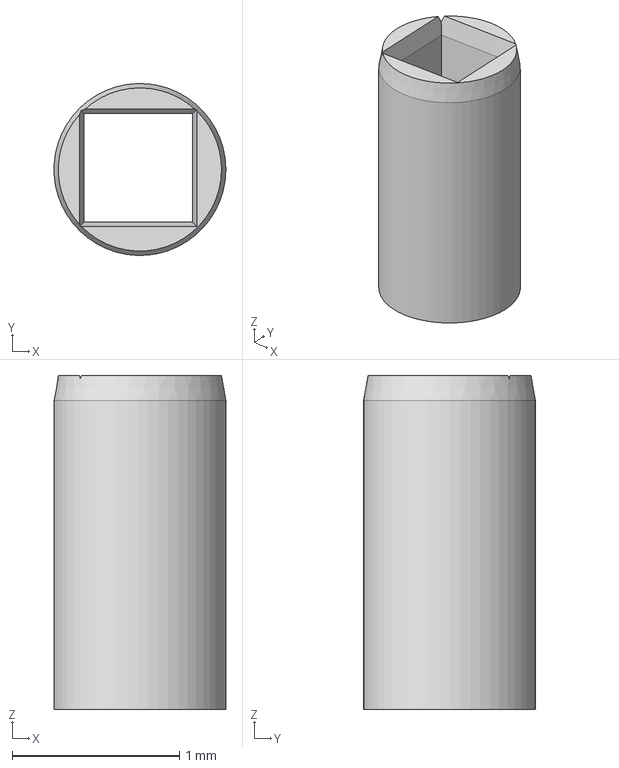
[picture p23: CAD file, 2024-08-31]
cad_design/2_motor_assembly/Assembly 3 - Soldering-Contacts (13).step
1.03 x 1.03 x 2.00 mm

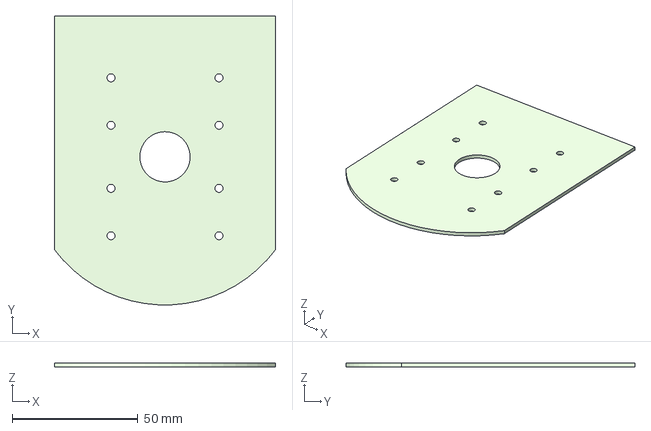
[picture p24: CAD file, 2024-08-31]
cad_design/4_motor_assembly/Assembly 1 - BasePlate.step
88.0 x 114.9 x 1.60 mm

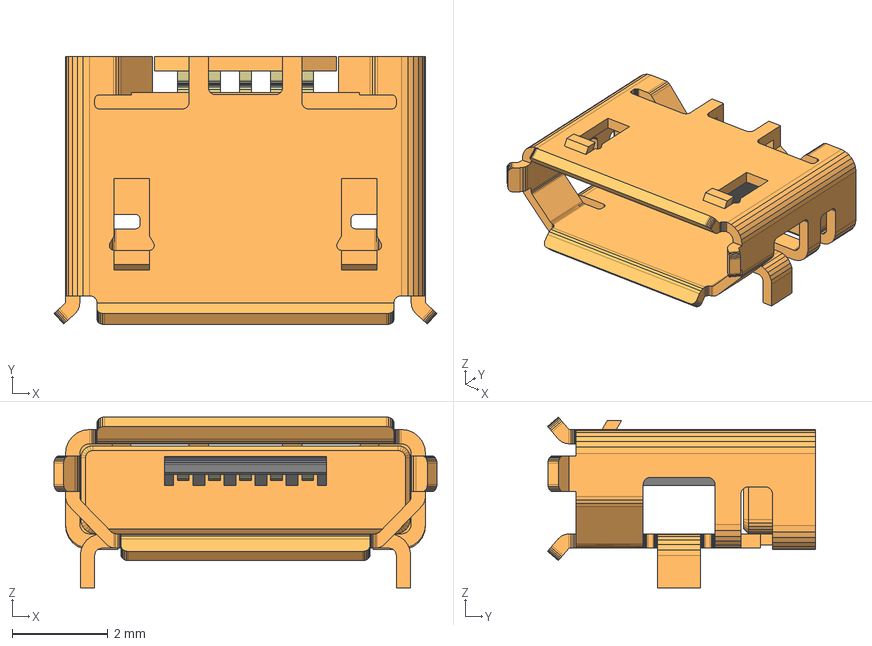
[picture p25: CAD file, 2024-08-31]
cad_design/2_motor_assembly/Assembly 3 - ab2_usb_micro_smd.wrl.step
8.00 x 5.60 x 3.57 mm

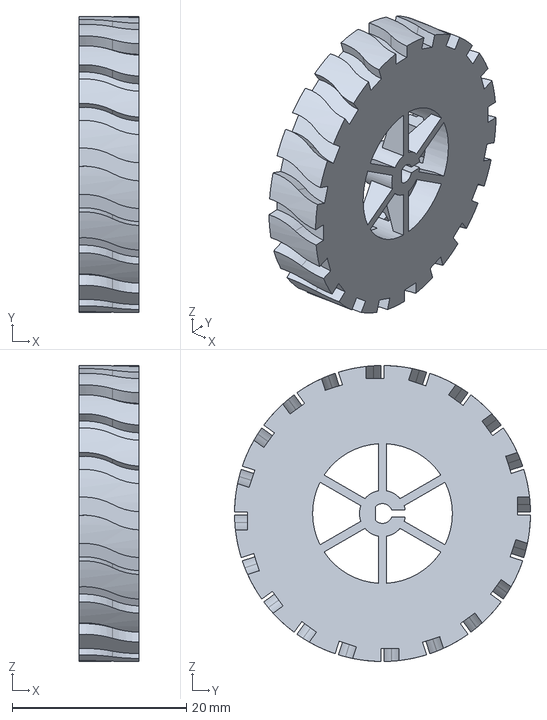
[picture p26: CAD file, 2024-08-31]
cad_design/4_motor_assembly/Assembly 1 - WHEEL.step
6.85 x 34.0 x 34.0 mm

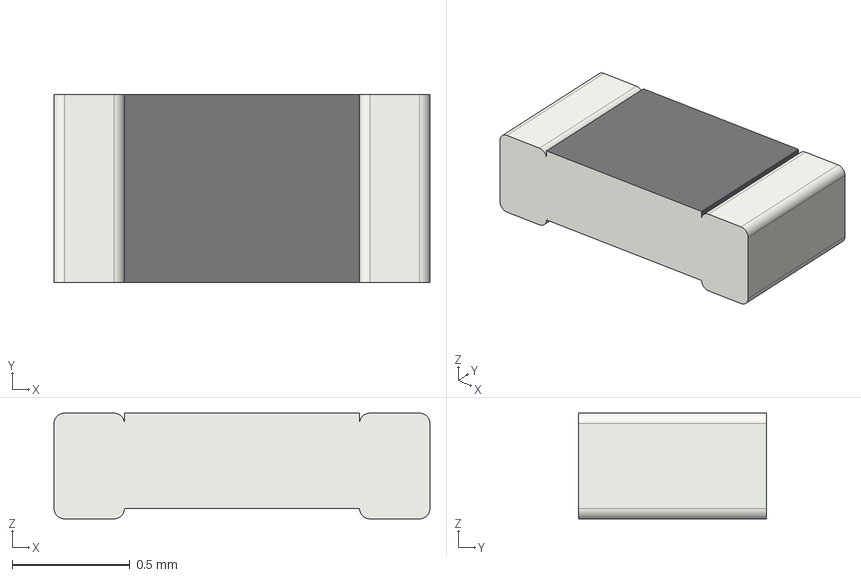
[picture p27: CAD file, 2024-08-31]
cad_design/2_motor_assembly/Assembly 3 - R_0603_1608Metric_2.step
1.60 x 0.8 x 0.45 mm

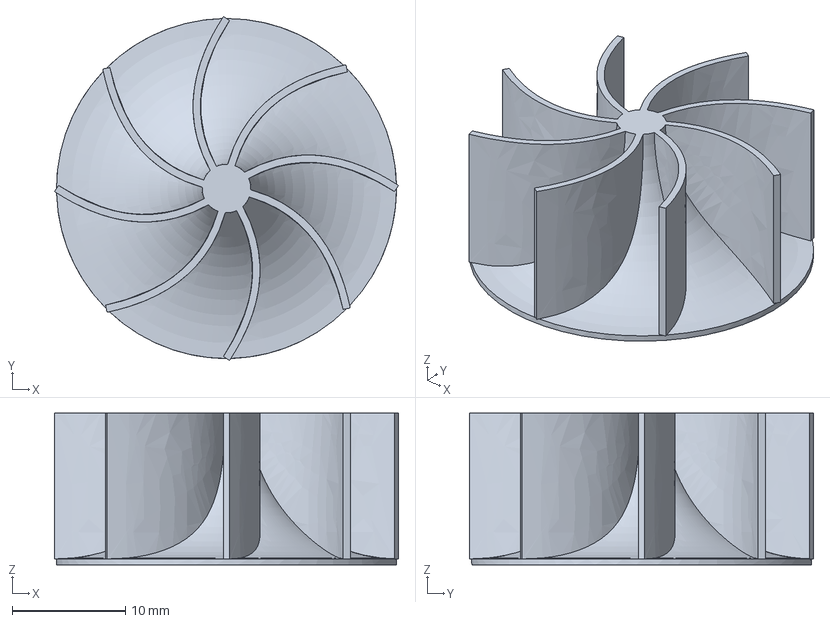
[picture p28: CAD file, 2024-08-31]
cad_design/4_motor_assembly/Assembly 1 - Impeller.step
30.4 x 30.4 x 13.4 mm

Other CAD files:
cad_design/4_motor_assembly/Assembly 1 - Mount 1_T.step
cad_design/2_motor_assembly/Assembly 3 - Soldering-Contacts (6).step
cad_design/4_motor_assembly/Assembly 1 - Part 12.step
cad_design/2_motor_assembly/Assembly 3 - PinHeader_1x04_P254mm_Vertical.step
cad_design/2_motor_assembly/Assembly 3 - 1020 Coreless Motor v3 v2 (1).step
cad_design/2_motor_assembly/Assembly 3 - 1020 Coreless Motor v3 v2.step
cad_design/2_motor_assembly/Assembly 3 - 3x4x2mm_tact_button.step
cad_design/2_motor_assembly/Assembly 3 - CP_Elec_63x77.step
cad_design/2_motor_assembly/Assembly 3 - CP_Elec_8x105.step
cad_design/2_motor_assembly/Assembly 3 - CQ assembly (1).step
cad_design/2_motor_assembly/Assembly 3 - CQ assembly (2).step
cad_design/2_motor_assembly/Assembly 3 - CQ assembly (3).step
cad_design/2_motor_assembly/Assembly 3 - CQ assembly (4).step
cad_design/2_motor_assembly/Assembly 3 - CQ assembly (5).step
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

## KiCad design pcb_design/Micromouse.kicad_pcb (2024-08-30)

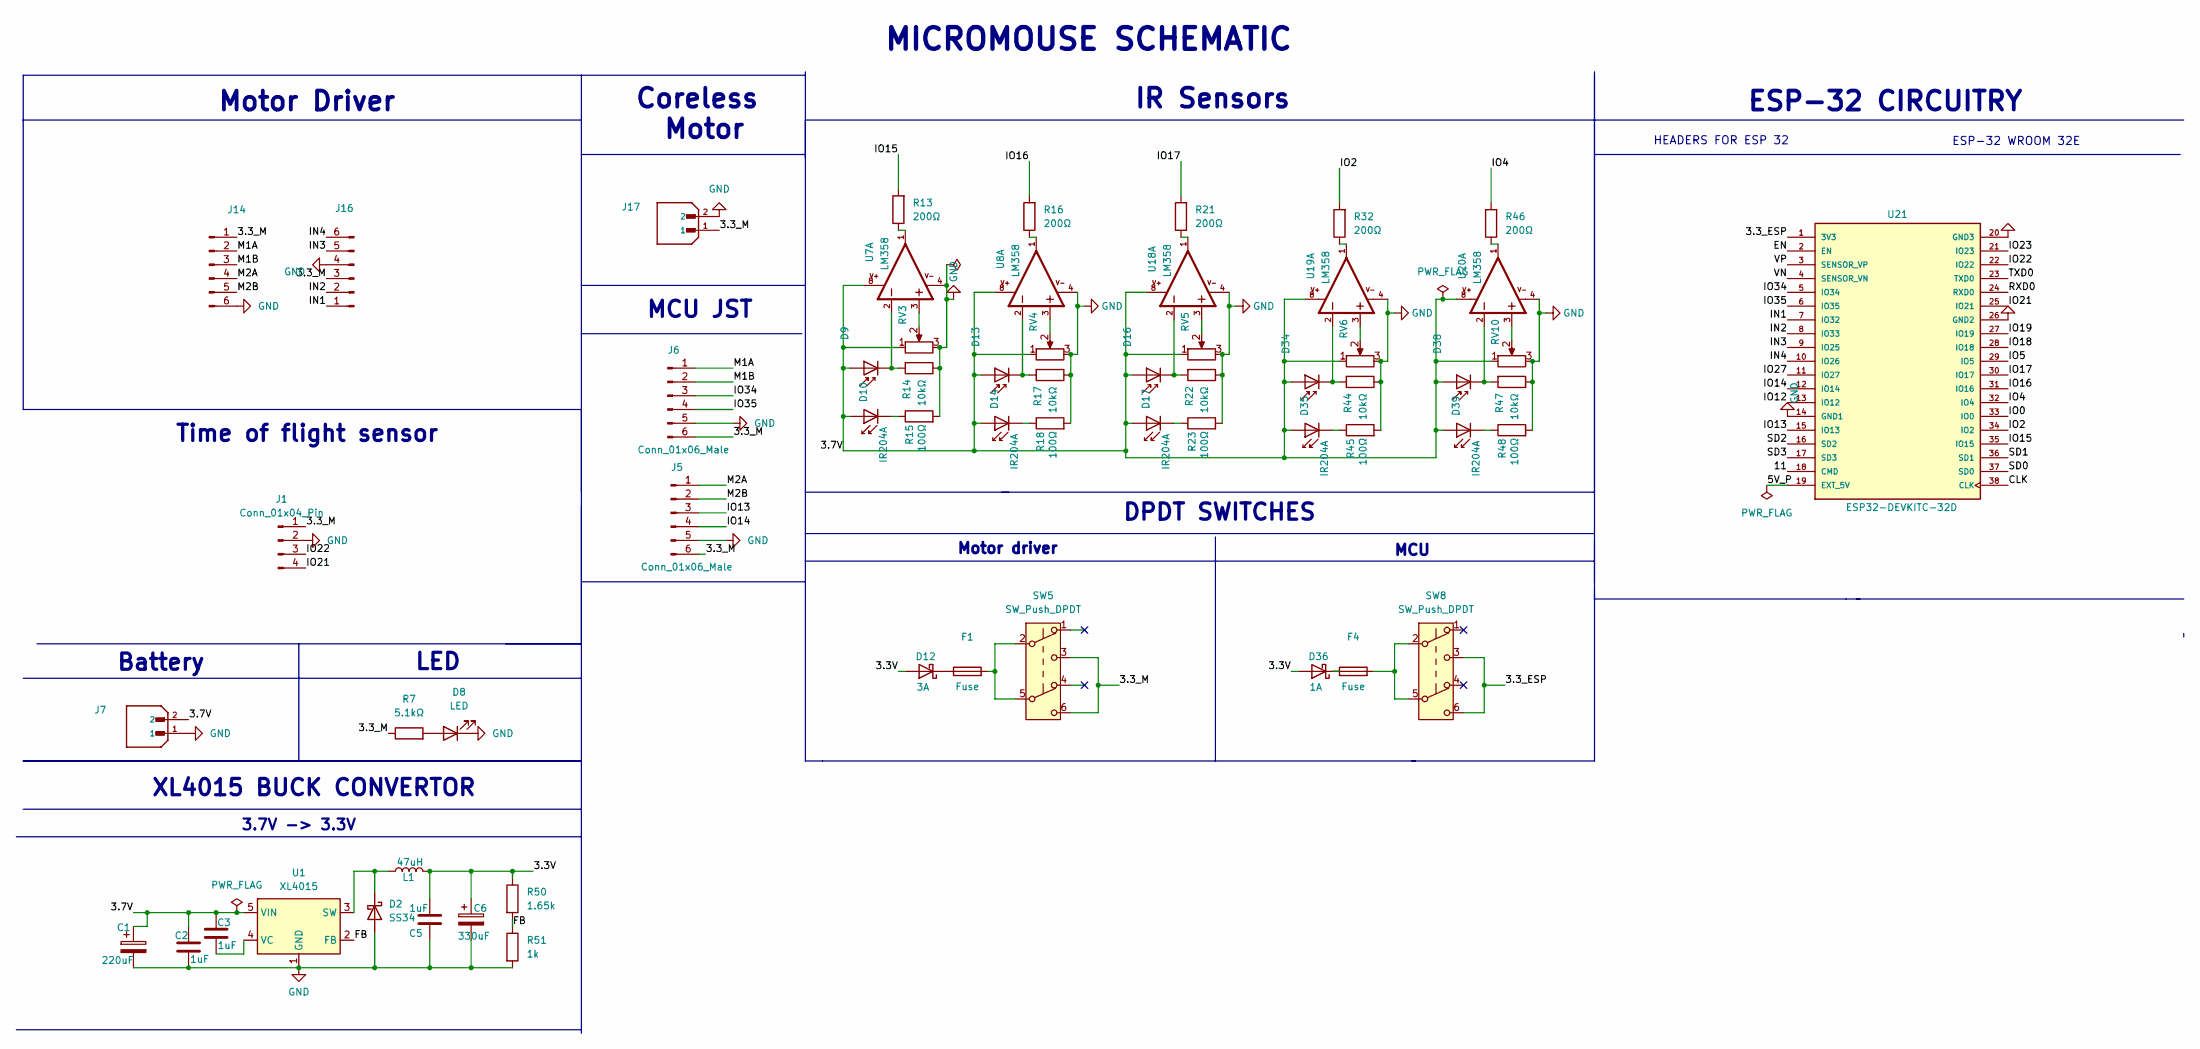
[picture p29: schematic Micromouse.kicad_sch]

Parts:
C1: 220uF; CP_Elec_6.3x7.7
C2, C3, C5: 1uF; C_0603_1608Metric
C6: 330uF; CP_Elec_8x10.5
D2: SS34; D_SMA
D8: LED; LED_0603_1608Metric
D9, D13, D16, D34, D38: D_Photo; LED2-2.54-D5.0MM
D10, D14, D17, D35, D39: IR204A; LED_D3.0mm_IRBlack
D12: 3A; D_SMB
D36: 1A; D_SMA
F1, F4: Fuse; RUEF160
J1: Conn_01x04_Pin; PinHeader_1x04_P2.54mm_Vertical
J5, J6: Conn_01x06_Male; PinHeader_1x06_P2.54mm_Vertical
J7, J17: B2B-XH-A_LF__SN_; JST_B2B-XH-A_LF__SN_; PARTREV N/A
J14, J16: Conn_01x06_Pin; PinHeader_1x06_P2.54mm_Vertical
L1: 47uH; L_10.4x10.4_H4.8
R7: 5.1kΩ; R_0603_1608Metric
R13, R16, R21, R32, R46: 200Ω; R_0603_1608Metric
R14, R17, R22, R44, R47: 10kΩ; R_0603_1608Metric
R15, R18, R23, R45, R48: 100Ω; R_0603_1608Metric
R50: 1.65k; R_0603_1608Metric
R51: 1k; R_0603_1608Metric
RV3, RV4, RV5, RV6, RV10: R_Potentiometer; TRIM_3362P-1-253LF123
SW5, SW8: SW_Push_DPDT; SW_TL2230OAF140
U1: XL4015; TO-263-5_TabPin3
U7, U8, U18, U19, U20: LM358; SOIC8_150MIL
U21: ESP32-DEVKITC-32D; MODULE_ESP32-DEVKITC-32D; PARTREV 4

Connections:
/3.3V: C5.1, C6.1, D12.2 (A), D36.2 (A), L1.2, R50.1
/3.3_ESP: SW8.3 (C), SW8.6 (C), U21.1 (3V3)
/3.3_M: J1.1, J5.6, J6.6, J14.1, J16.3, J17.1, R7.1, SW5.3 (C), SW5.6 (C)
/3.7V: C1.1, C2.1, C3.1, D9.2 (A), D10.2 (A), D13.2 (A), D14.2 (A), D16.2 (A), D17.2 (A), D34.2 (A), D35.2 (A), D38.2 (A), D39.2 (A), J7.2, RV3.1, RV4.1, RV5.1, RV6.1, RV10.1, U1.5 (VIN), U7.8, U8.8, U18.8, U19.8, U20.8
/5V_P: U21.19 (EXT_5V)
/11: U21.18 (CMD)
/CLK: U21.38 (CLK)
/EN: U21.2 (EN)
/FB: R50.2, R51.1, U1.2 (FB)
/IN1: J16.1, U21.7 (IO32)
/IN2: J16.2, U21.8 (IO33)
/IN3: J16.5, U21.9 (IO25)
/IN4: J16.6, U21.10 (IO26)
/IO0: U21.33 (IO0)
/IO2: R32.2, U21.34 (IO2)
/IO4: R46.2, U21.32 (IO4)
/IO5: U21.29 (IO5)
/IO12: U21.13 (IO12)
/IO13: J5.3, U21.15 (IO13)
/IO14: J5.4, U21.12 (IO14)
/IO15: R13.2, U21.35 (IO15)
/IO16: R16.2, U21.31 (IO16)
/IO17: R21.2, U21.30 (IO17)
/IO18: U21.28 (IO18)
/IO19: U21.27 (IO19)
/IO21: J1.4, U21.25 (IO21)
/IO22: J1.3, U21.22 (IO22)
/IO23: U21.21 (IO23)
/IO27: U21.11 (IO27)
/IO34: J6.3, U21.5 (IO34)
/IO35: J6.4, U21.6 (IO35)
/M1A: J6.1, J14.2
/M1B: J6.2, J14.3
/M2A: J5.1, J14.4
/M2B: J5.2, J14.5
/RXD0: U21.24 (RXD0)
/SD0: U21.37 (SD0)
/SD1: U21.36 (SD1)
/SD2: U21.16 (SD2)
/SD3: U21.17 (SD3)
/TXD0: U21.23 (TXD0)
/VN: U21.4 (SENSOR_VN)
/VP: U21.3 (SENSOR_VP)
GND: C1.2, C2.2, C5.2, C6.2, D2.2 (A), D8.1 (K), J1.2, J5.5, J6.5, J7.1, J14.6, J16.4, J17.2, R14.1, R15.2, R17.1, R18.2, R22.1, R23.2, R44.1, R45.2, R47.1, R48.2, R51.2, RV3.3, RV4.3, RV5.3, RV6.3, RV10.3, U1.1 (GND), U7.4, U8.4, U18.4, U19.4, U20.4, U21.14 (GND1), U21.20 (GND3), U21.26 (GND2)
unnamed: D2.1 (K), L1.1, U1.3 (SW)
unnamed: D8.2 (A), R7.2
unnamed: D9.1 (K), R14.2, U7.2
unnamed: D10.1 (K), R15.1
unnamed: D12.1 (K), F1.1
unnamed: D13.1 (K), R17.2, U8.2
unnamed: D14.1 (K), R18.1
unnamed: D16.1 (K), R22.2, U18.2
unnamed: D17.1 (K), R23.1
unnamed: D34.1 (K), R44.2, U19.2
unnamed: D35.1 (K), R45.1
unnamed: D36.1 (K), F4.1
unnamed: D38.1 (K), R47.2, U20.2
unnamed: D39.1 (K), R48.1
unnamed: F1.2, SW5.2 (B), SW5.5 (B)
unnamed: F4.2, SW8.2 (B), SW8.5 (B)
unnamed: R13.1, U7.1
unnamed: R16.1, U8.1
unnamed: R21.1, U18.1
unnamed: R32.1, U19.1
unnamed: R46.1, U20.1
unnamed: RV3.2, U7.3
unnamed: RV4.2, U8.3
unnamed: RV5.2, U18.3
unnamed: RV6.2, U19.3
unnamed: RV10.2, U20.3
unnamed: C3.2, U1.4 (VC)

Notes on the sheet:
Coreless Motor
MICROMOUSE SCHEMATIC
ESP-32 WROOM 32E
Battery
ESP-32 CIRCUITRY
DPDT SWITCHES
IR Sensors
MCU JST
3.7V -> 3.3V
HEADERS FOR ESP 32
MCU
XL4015 BUCK CONVERTOR
Motor driver
LED
Time of flight sensor
Motor Driver

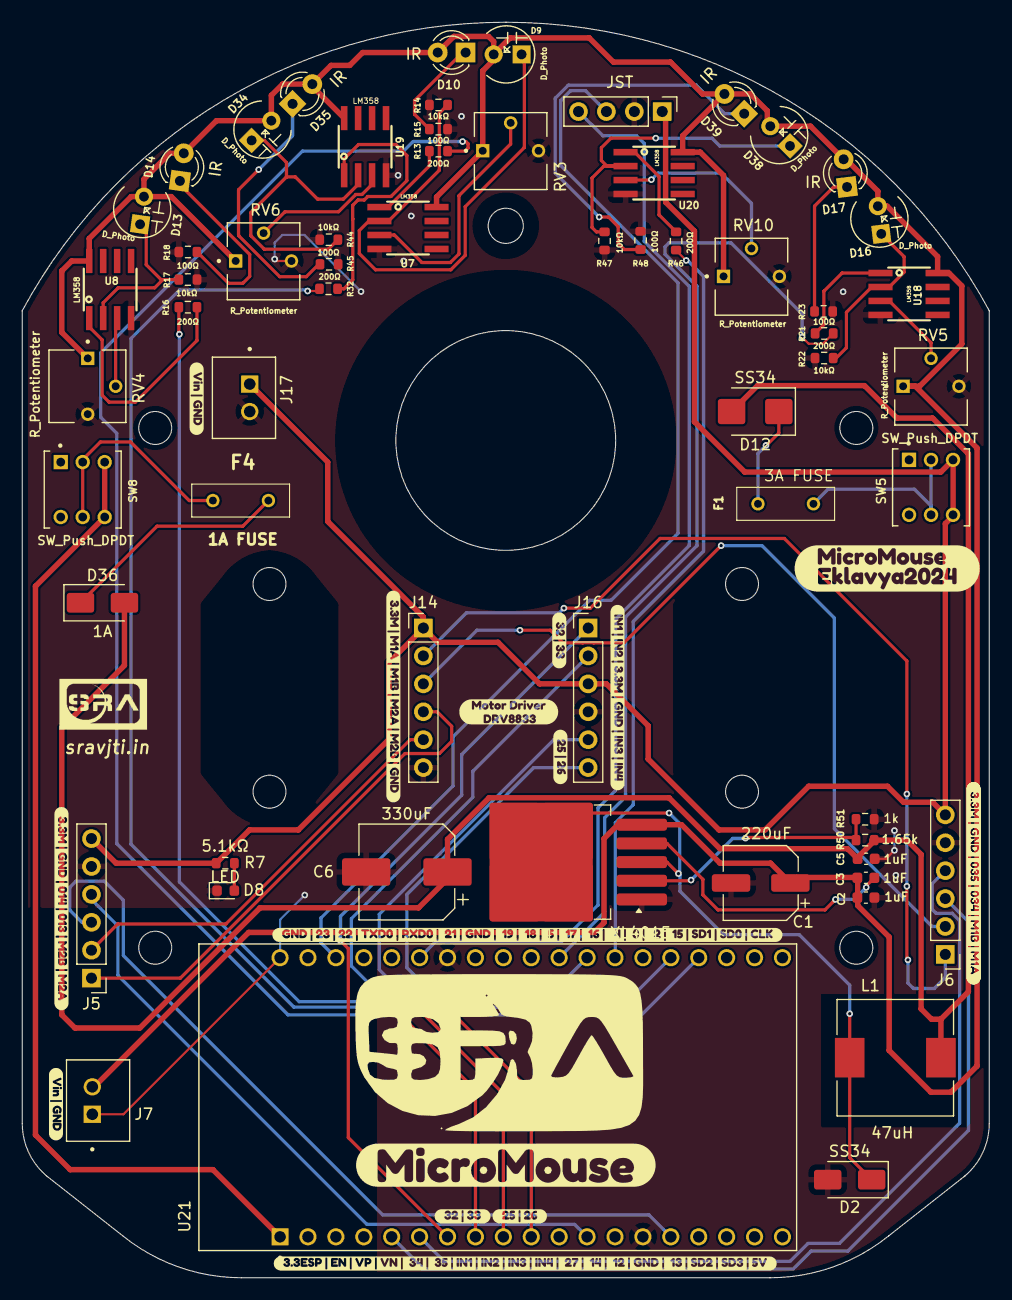
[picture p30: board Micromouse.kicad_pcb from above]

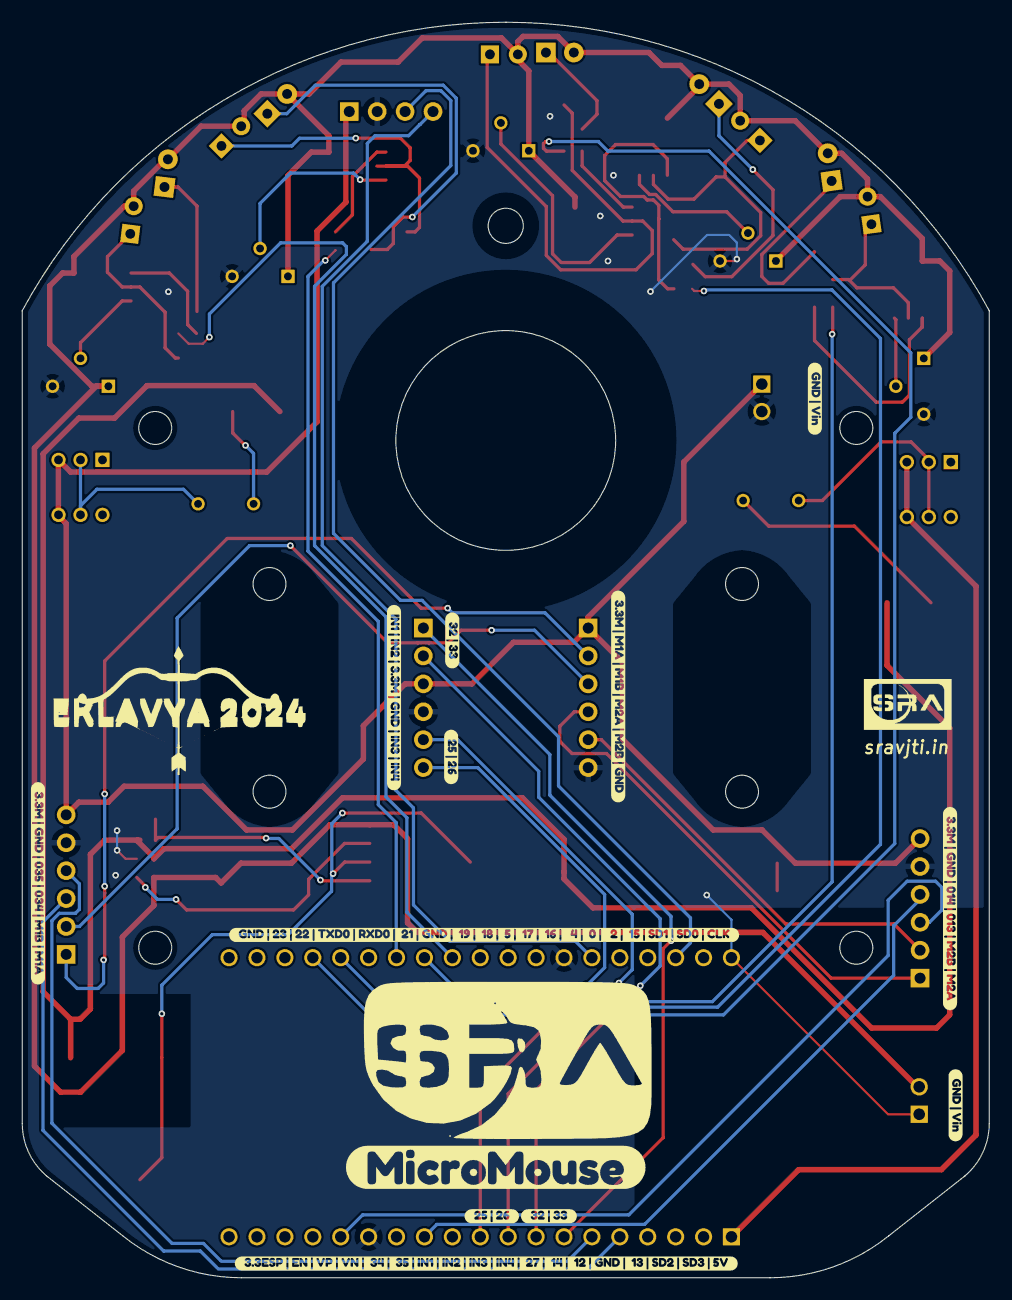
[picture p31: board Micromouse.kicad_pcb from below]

Board: 2 copper layers, 88.0 x 114.3 mm, 90 parts (13 on the bottom side), 52 nets.

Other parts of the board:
kibuzzard-66C4A04A, kibuzzard-66C4A04A#2: G***; kibuzzard-66C4A04A
kibuzzard-66C4A074, kibuzzard-66C4A074#2: G***; kibuzzard-66C4A074
kibuzzard-66C49AF5, kibuzzard-66C49AF5#2, kibuzzard-66C49AF5#3, kibuzzard-66C49AF5#4: G***; kibuzzard-66C49AF5
kibuzzard-66C49BB8, kibuzzard-66C49BB8#2: G***; kibuzzard-66C49BB8
kibuzzard-66C49C11, kibuzzard-66C49C11#2: G***; kibuzzard-66C49C11
kibuzzard-66C49C59, kibuzzard-66C49C59#2, kibuzzard-66C49C59#3, kibuzzard-66C49C59#4: G***; kibuzzard-66C49C59
kibuzzard-66C308A6: G***; kibuzzard-66C308A6
kibuzzard-66C486A2, kibuzzard-66C486A2#2: G***; kibuzzard-66C486A2
kibuzzard-66C2808F: G***; kibuzzard-66C2808F
kibuzzard-66C28409: G***; kibuzzard-66C28409
kibuzzard-66C30793, kibuzzard-66C30793#2: G***; kibuzzard-66C30793
kibuzzard-66C30870: G***; kibuzzard-66C30870
kibuzzard-66C31908, kibuzzard-66C31908#2: G***; kibuzzard-66C31908
kibuzzard-66C31993, kibuzzard-66C31993#2, kibuzzard-66C31993#3: G***; kibuzzard-66C31993

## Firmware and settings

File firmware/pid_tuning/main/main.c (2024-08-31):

#include <stdio.h>
#include <math.h>
#include "driver/gpio.h"
#include "freertos/FreeRTOS.h"
#include "freertos/task.h"
#include "driver/adc.h"
#include "driver/ledc.h"

#define LEFTMOST_IR   ADC2_CHANNEL_5
#define RIGHTMOST_IR   ADC2_CHANNEL_6

#define LEFT_MOTOR_A   32
#define LEFT_MOTOR_B   33
#define RIGHT_MOTOR_B   25
#define RIGHT_MOTOR_A   26

#define Standard_Speed  60

ledc_timer_config_t pwm_timer;
ledc_channel_config_t pwm_channel[2];

int left_error_previous;
int right_error_previous;

int left_error_new;
int right_error_new;

float Kp = 1;
float Kd = 0.1;

int left_pwm_output;
int right_pwm_output;

static void init_pwm() {
    adc2_config_channel_atten(LEFTMOST_IR, ADC_ATTEN_DB_11);
    adc2_config_channel_atten(RIGHTMOST_IR, ADC_ATTEN_DB_11);

    pwm_timer.duty_resolution = LEDC_TIMER_10_BIT;
    pwm_timer.freq_hz = 1000;
    pwm_timer.speed_mode = LEDC_HIGH_SPEED_MODE;
    pwm_timer.timer_num = LEDC_TIMER_0;
    pwm_timer.clk_cfg = LEDC_AUTO_CLK;
    ledc_timer_config(&pwm_timer);

    pwm_channel[0].channel = LEDC_CHANNEL_0;
    pwm_channel[0].duty = 0;
    pwm_channel[0].gpio_num = LEFT_MOTOR_A;
    pwm_channel[0].speed_mode = LEDC_HIGH_SPEED_MODE;
    pwm_channel[0].hpoint = 0;
    pwm_channel[0].timer_sel = LEDC_TIMER_0;
    ledc_channel_config(&pwm_channel[0]);

    pwm_channel[1].channel = LEDC_CHANNEL_1;
    pwm_channel[1].duty = 0;
    pwm_channel[1].gpio_num = RIGHT_MOTOR_A;
    pwm_channel[1].speed_mode = LEDC_HIGH_SPEED_MODE;
    pwm_channel[1].hpoint = 0;
    pwm_channel[1].timer_sel = LEDC_TIMER_0;
    ledc_channel_config(&pwm_channel[1]);
}

int left_ir_error() {
    int new_read_left;
    int expected_read_left = 3000;  // here the readings of the left ir sensor to be achieved will be given
    int left_error;
    adc2_get_raw(LEFTMOST_IR, ADC_WIDTH_BIT_DEFAULT, &new_read_left);
    if (new_read_left >= expected_read_left) {
        left_error = -(expected_read_left - new_read_left);
    } else {
        left_error = 0;
    }
    return left_error;
}

int right_ir_error() {
    int new_read_right;
    int expected_read_right = 3000;  // here the readings of the right ir sensor to be achieved will be given
    int right_error;
    adc2_get_raw(RIGHTMOST_IR, ADC_WIDTH_BIT_DEFAULT, &new_read_right);
    if (new_read_right >= expected_read_right) {
        right_error = -(expected_read_right - new_read_right);
    } else {
        right_error = 0;
    }
    return right_error;
}

void app_main(void)
{
    init_pwm();

    while(1) {
        left_error_new = left_ir_error();
        right_error_new = right_ir_error();


        if (left_error_new == 0) {
            left_pwm_output = 0;
        } else {
            left_pwm_output = round(Kp*left_error_new + Kd*(left_error_previous - left_error_new));   
        }

        if (right_error_new == 0) {
            right_pwm_output = 0;
        } else {
            right_pwm_output = round(Kp*right_error_new + Kd*(right_error_previous - right_error_new));
        }
        

        printf("left_pwm_output = %d \n", left_pwm_output);
        printf("right_pwm_output = %d \n", right_pwm_output);
        
        // mapping of updated left and right pid pwm output

        ledc_set_duty(pwm_channel[0].speed_mode, pwm_channel[0].channel, Standard_Speed + left_pwm_output);
        ledc_update_duty(pwm_channel[0].speed_mode, pwm_channel[0].channel);
        ledc_set_duty(pwm_channel[1].speed_mode, pwm_channel[1].channel, Standard_Speed + right_pwm_output);
        ledc_update_duty(pwm_channel[1].speed_mode, pwm_channel[1].channel);

        left_error_previous = left_error_new;
        right_error_previous = right_error_new;

        vTaskDelay(100 / portTICK_PERIOD_MS);
    }
}
